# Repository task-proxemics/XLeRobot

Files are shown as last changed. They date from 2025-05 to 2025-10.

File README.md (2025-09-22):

# [XLeRobot 🤖](https://xlerobot.readthedocs.io/en/latest/index.html)




<a href="https://xlerobot.readthedocs.io/en/latest/index.html">
  front
</a>





---

**🚀 Bringing Embodied AI to Everyone - Cheaper Than an iPhone! 📱**  
**💵 Starts from $660 cost and ⏰ <4hrs total assembly time!!**

*Built upon the giants: [LeRobot](https://github.com/huggingface/lerobot), [SO-100/SO-101](https://github.com/TheRobotStudio/SO-ARM100), [Lekiwi](https://github.com/SIGRobotics-UIUC/LeKiwi), [Bambot](https://github.com/timqian/bambot)*

<table>
  <tr>
    <td></td>
    <td></td>
    <td></td>
  </tr>
  <tr>
    <td></td>
    <td></td>
    <td></td>
  </tr>
  <tr>
    <td></td>
    <td></td>
    <td></td>
  </tr>
</table>

---

# 📰 News 
- 2025-09-22: **Hardware Assembly Video Tutorial** availabe at [Youtube](https://www.youtube.com/watch?v=upB1CEFeOlk) and [Bilibili](https://www.bilibili.com/video/BV1AGWFzUEJf/). Thanks WOWROBO for making this video!
- 2025-09-09: **Developer Assembly kit (excluding battery and IKEA cart) ready for purchase** in [China (Taobao) for **3699￥**](https://e.tb.cn/h.SZFbBgZABZ8zRPe?tk=ba514rTBRjQ) and [world-wide for **579\$**](https://shop.wowrobo.com/products/xlerobot-dual-arm-mobile-household-robot-kit?variant=47297659961561). _(In collaboration with **Wowrobo**, one of the official collaborators with Huggingface SO101 arm, they have sold 5k+ SO101 arm worldwide with great customer feedback.)_
  
  - Non-profit, I personally don't earn any from this. I also asked Wowrobo to set the price as low as possible.
  - This is only the assembly kit for developers, please check documentation website and this repo for available codes and tutorials before you purchase.
- 2025-09-09: Joined [Embodied AI Home Robot Hackathon](https://www.seeedstudio.com/embodied-ai-worldwide-hackathon-home-robot.html) (Oct 25–26, Bay Area) held by **SEEED x Nvidia x Huggingface** as mentor! [Register HERE](https://docs.google.com/forms/d/e/1FAIpQLSdYYDegdgIypxuGJNLcoc8kbdmU4jKgl49zg4X-107LAmBN4g/viewform).
- 

- 2025-08-30: XLeRobot 0.3.0 Release with final outfit touch up and household chores showcase demos. 

- 2025-07-30: [Control XLeRobot in real life](https://xlerobot.readthedocs.io/en/latest/software/index.html) with **keyboard/Xbox controller/Switch joycon** in the wild anywhere. All bluetooth, no wifi needed and zero latency.
- rea

- 2025-07-08: [**Simulation**](https://xlerobot.readthedocs.io/en/latest/simulation/index.html) with updated urdfs, control scripts (support Quest3 VR, keyboard, Xbox controller, switch joycon), support for new hardware and cameras, RL environment. Get started in 15 min.
-  vr

- 2025-07-01: [**Documentation** website](https://xlerobot.readthedocs.io/en/latest/index.html) out for more orgainized tutorials, demos and resources.

- 2025-06-13: [**XLeRobot 0.2.0**](https://xlerobot.readthedocs.io) hardware setup, the 1st version fully capable for autonomous household tasks, starts from 660$. 

---

## 💵 Total Cost 💵

> [!NOTE] 
> Cost excludes 3D printing, tools, shipping, and taxes.

| Price (Buy all the parts yourself) | US | EU | CN | IN |
| --- | --- | --- | --- | --- |
| **Basic** (use your laptop, single RGB head cam) | **~$660** | **~€680** | **~¥3999** | **~₹87000** |
| ↑ Stereo dual-eye RGB head cam | +$30 | +€30 | +¥199 | +₹6550 |
| + RasberryPi | +$79 | +€79 | +¥399 | +₹7999 |
| ↑ RealSense RGBD head cam | +$220 | +€230 | +¥1499 | +₹35726 |

---
## 🚀 Get Started 🚀

> [!NOTE] 
> If you are totally new to programming, please spend at least a day to get yourself familiar with basic Python, Ubuntu and Github (with the help of Google and AI). At least you should know how to setup ubuntu system, git clone, pip install, use intepreters (VS Code, Cursor, Pycharm, etc.) and directly run commands in the terminals.

1. 💵 **Buy your parts**: [Bill of Materials](https://xlerobot.readthedocs.io/en/latest/hardware/getting_started/material.html)
2. 🖨️ **Print your stuff**: [3D printing](https://xlerobot.readthedocs.io/en/latest/hardware/getting_started/3d.html)
3. 🔨 ~~Avengers~~: [**Assemble**!](https://xlerobot.readthedocs.io/en/latest/hardware/getting_started/assemble.html)
4. 💻 **Software**: [Get your robot moving!](https://xlerobot.readthedocs.io/en/latest/software/index.html)

---

## Contribute

**👋 Want to contribute to XLeRobot?**
Please refer to [CONTRIBUTING.md](CONTRIBUTING.md) for guidance on how to get involved!

**Main Contributors**

- [Gaotian/Vector Wang](https://vector-wangel.github.io/)
- [Zhuoyi Lu](https://lzhuoyi.github.io/Zhuoyi_Lu.github.io/): RL sim2real deploy, teleop on real robot (Xbox, VR, Joycon)
- Yiyang Huang: RL & VLA implementation (ongoing)
- YCP: WebUI for remote control (ongoing)
- [Lixing Zhang](lixingzhang.com): Hardware design improvements
- Nicole Yue: Documentation website setup
- Yuesong Wang: Mujoco simulation

This is just a small brick in the pyramid, made possible by [LeRobot](https://github.com/huggingface/lerobot), [SO-100](https://github.com/TheRobotStudio/SO-ARM100), [Lekiwi](https://github.com/SIGRobotics-UIUC/LeKiwi), and [Bambot](https://github.com/timqian/bambot). Thanks to all the talented contributors behind these detailed and professional projects.

Looking forward to collaborating with anyone interested in contributing to this project!

## About me

[Gaotian/Vector Wang](https://vector-wangel.github.io/)

I am a CS graduate student at Rice University [RobotPi Lab](https://robotpilab.github.io/), focusing on robust object manipulation, where we propse virtual cages and funnels and physics-aware world models to close the Sim2real gap and achieve robust manipulation under uncertainties. One of my papers, Caging in Time, has recently been accepted by International Journal of Robotics Research (IJRR).

I built XLeRobot as a personal hobby to instantiate my research theory, also to provide a low-cost platform for people who are interested in robotics and embodied AI to work with. 

Star History Chart (https://star-history.com/#Vector-Wangel/XLeRobot&Timeline)
---

## Citation

If you want, you can cite this work with:

```bibtex
@misc{wang2025xlerobot,
    author = {Wang, Gaotian and Lu, Zhuoyi},
    title = {XLeRobot: A Practical Low-cost Household Dual-Arm Mobile Robot Design for General Manipulation},
    howpublished = "\url{https://github.com/Vector-Wangel/XLeRobot}",
    year = {2025}
}
```
---Generated Image August 27, 2025 - 4_58PM

## 🪧 Disclaimer 🪧

> [!NOTE]
> If you build, buy, or develop a XLeRobot based on this repo, you will be fully responsible for all the physical and mental damages it does to you or others.

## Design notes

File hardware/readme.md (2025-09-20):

Here stores the .3mf file of XLeRobot 0.3.0 for 3D printing.



Note that the 3D Printing files are only to store the models. It’s suggested to place, orient, and add supports yourself to ensure the best printing quality.

## Notes

- The .3mf file contains soft finray fingers that need to be printed with TPU95A. If you want original SO101 finger, just download the original SO101 .stl file.
- d2e57534a9e55a3d4dc0d644242cd044
- The .3mf file contains 2 version of the single RGB head camera connector and shell, one for webcam & realsense, the other for the cheaper camera same as the hand camera.
- 

- No need to adjust the base connector this time, just print the washers and insert them into the IKEA cart for the best base support.
- 

---

- Update 20.09.2025 by Lix: New gimbal designs can be found in the two mesh files:
    - Gimbal_Pitch_Holder_d435.stl: For Intel Realsense D435 or similar RGBD camera.
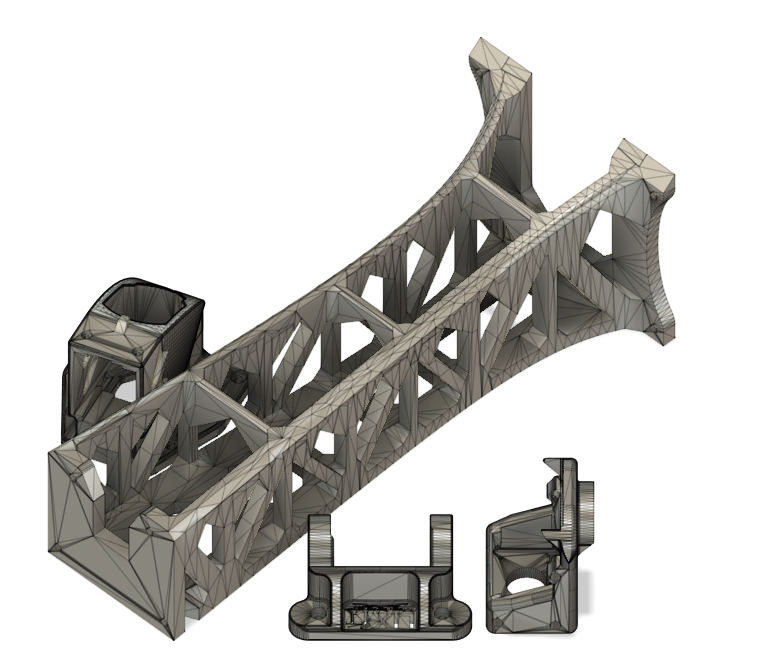
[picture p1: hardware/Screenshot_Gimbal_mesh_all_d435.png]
d435
    
    - Gimbal_Pitch_Holder_d455.stl: For Intel Realsense D455 or similar RGBD camera.
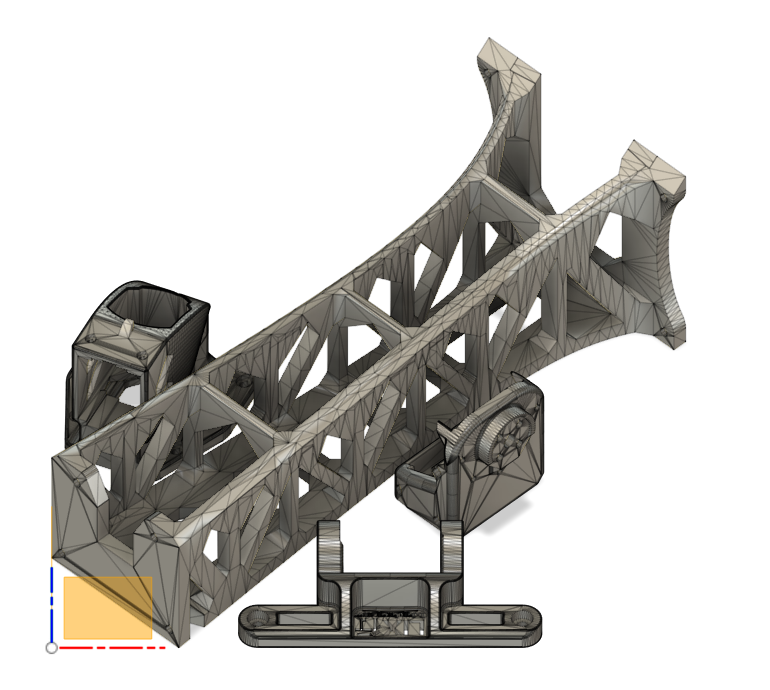
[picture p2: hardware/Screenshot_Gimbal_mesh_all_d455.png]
d455


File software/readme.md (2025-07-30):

## Updates

This folder mimics the official lerobot folder with XLeRobot robot file, configs and demo codes.

- SO100/SO101 control codes: These codes should be compatible to both SO100 and SO101, even if you just keep the name in the codes as so100. 

  - Keyboard Joint control
  - Keyboard EE control with my own analytical IK
  - Keyboard EE control for dual arm setup with my own analytical IK

- Computer Vision codes
  - simple_so100_yolo_ee_control.py: YOLO for object detection and segmentation, real-time tracking with the hand camera
  - 

Real-time test on YOLO-based control for object tracking:

https://github.com/user-attachments/assets/e0eb4aa5-bce2-404c-b9ed-380a83c852fd

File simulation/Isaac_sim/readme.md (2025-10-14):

Here's usd file for XLeRobot in Isaac Sim.

We are currently in collaboration with Lightwheel AI. 

And we highly recommend to run XLeRobot in Isaac Sim with their provided environment Leisaac.

https://github.com/LightwheelAI/leisaac

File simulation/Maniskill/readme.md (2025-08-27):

Here's the urdf files, assets, and EE control codes in Maniskill.

## Update

XLeRobot files are exclusively listed instead of borrowing fetch's name. So there are a few more modifications need to be done to run XLeRobot in the ReplicaCAD scene, in addtion to the [previous tutorial](https://xlerobot.readthedocs.io/en/latest/simulation/getting_started/index.html) 

For new robot ids, you need to add them to ReplicaCAD scene first.


As well as the agent/robots/init.py


## Run the examples

You also need to add the robot id in the command. For example, if you want to run a single-arm version of XLeRobot:

```
python -m mani_skill.examples.demo_ctrl_action_ee_keyboard_single -e "ReplicaCAD_SceneManipulation-v1" -r "xlerobot_single"  --render-mode="human" --shader="rt-fast" -c "pd_joint_delta_pos"
```

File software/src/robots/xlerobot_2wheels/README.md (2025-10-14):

# XLeRobot 2-Wheels (Differential Drive)

This is a modified version of XLeRobot that uses a 2-wheel differential drive base instead of the original 3-wheel omni wheel base.

## Key Changes from Original XLeRobot

### Hardware Changes
- **Wheels**: Reduced from 3 omni wheels to 2 differential drive wheels
- **Motor IDs**: 
  - Left wheel: Motor ID 9
  - Right wheel: Motor ID 10
  - Removed: Back wheel (previously Motor ID 8)

### Kinematics Changes
- **Movement**: Only supports forward/backward (x) and rotation (θ)
- **No lateral movement**: Cannot move sideways (y) like the omni wheel version
- **Differential drive equations**:
  - Left wheel speed = (v - ω*L/2) / r
  - Right wheel speed = (v + ω*L/2) / r
  - Where v = linear velocity, ω = angular velocity, L = wheelbase, r = wheel radius

### Configuration Parameters
- `wheel_radius`: 0.05 meters (default)
- `wheelbase`: 0.25 meters (default)
- These can be adjusted in the config files

### Control Interface
- **Forward/Backward**: 'i'/'k' keys
- **Rotate Left/Right**: 'u'/'o' keys
- **Speed Control**: 'n'/'m' keys (3 speed levels)
- **No lateral movement keys**: 'j'/'l' keys removed

## Usage

### Running the Host (on robot hardware)
```bash
PYTHONPATH=src python -m lerobot.robots.xlerobot_2wheels.xlerobot_2wheels_host --robot.id=my_xlerobot_2wheels
```

### Running the Teleop Client
```bash
PYTHONPATH=src python -m examples.xlerobot_2wheels.teleoperate_Keyboard
```

### Direct Connection (no ZMQ)
```python
from lerobot.robots.xlerobot_2wheels import XLerobot2Wheels, XLerobot2WheelsConfig

config = XLerobot2WheelsConfig()
robot = XLerobot2Wheels(config)
robot.connect()
```

## Files Structure

- `xlerobot_2wheels.py`: Main robot class with differential drive kinematics
- `xlerobot_2wheels_client.py`: ZMQ client for remote control
- `xlerobot_2wheels_host.py`: ZMQ host running on robot hardware
- `config_xlerobot_2wheels.py`: Configuration classes
- `__init__.py`: Package initialization

## Key Differences from Original

1. **State Features**: Removed `y.vel` from state features (only `x.vel` and `theta.vel`)
2. **Motor Configuration**: Only 2 base motors instead of 3
3. **Kinematics Functions**: 
   - `_body_to_wheel_raw()`: Implements differential drive forward kinematics
   - `_wheel_raw_to_body()`: Implements differential drive inverse kinematics
4. **Control Interface**: Simplified to only support differential drive movements

## Advantages of Differential Drive

1. **Simpler Hardware**: Only 2 wheels instead of 3
2. **Lower Cost**: Fewer motors and simpler mechanical design
3. **Easier Maintenance**: Less complex wheel system
4. **Better for Indoor**: More suitable for flat indoor environments

## Limitations

1. **No Lateral Movement**: Cannot move sideways without rotating first
2. **Less Maneuverable**: Requires more complex maneuvers for precise positioning
3. **Wheel Slip**: May experience wheel slip on uneven surfaces

## Migration from Original XLeRobot

To migrate from the original 3-wheel version:

1. Update motor IDs in hardware configuration
2. Remove the back wheel motor
3. Update control code to use only forward/backward and rotation commands
4. Adjust movement strategies to account for no lateral movement capability

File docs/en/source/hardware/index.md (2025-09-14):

# Hardware

## 💵 Total Cost 💵

> Cost excludes 3D printing, tools, shipping, and taxes.
> 

| Price | US | EU | CN | IN |
| --- | --- | --- | --- | --- |
| **Basic** (use your laptop, single RGB head cam) | **~$660** | **~€680** | **~¥3999** | **~₹87000** |
| ↑ Stereo dual-eye RGB head cam | +$30 | +€30 | +¥199 | +₹6550 |
| + RaspberryPi | +$79 | +€79 | +¥399 | +₹7999 |
| ↑ RealSense RGBD head cam | +$220 | +€230 | +¥1499 | +₹35726 |

## 🚀 Get Started 🚀

##### [🛒 Bill of Material](getting_started/material)

##### [🖨️ 3D Printing](getting_started/3d)

##### [🔨 Assembly](getting_started/assemble)

##### [🛠️ Hardware Intro](hardware_intro/index)

---

```{toctree}
:caption: Get started
getting_started/material
getting_started/3d
getting_started/assemble
```

```{toctree}
:caption: Hardware Intro
hardware_intro/index
```

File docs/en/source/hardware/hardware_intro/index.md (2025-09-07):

## 🛠️ Hardware Intro 🛠️

**XLeRobot** = Lekiwi + 1x SO-100/SO-101 arm + **IKEA RÅSKOG Cart** + **Anker Battery**

= 2x SO-100/SO-101 Arms + 3x omni wheels + RaspberryPi + **IKEA RÅSKOG Cart** + **Anker Battery**

#### 📜Basic Specs

- **Weight**📏: ~12kg. Easily lifted by an adult.
- **Workspace**🦾:
    - Height range: ~0.5m-1.25m from the ground
    - Width range: ~0.36m from the cart edge.
    - Capable of many household tasks.
- **Battery**🔋:
    - 300W max out: sufficient for powering 12V version dual arm + lekiwi base + RaspberryPi (~180W max)
    - 288Wh capacity: can normally operate for 10hrs+
    - 280W max in: 1hr to get fully charged
    - Optional solar panels☀: for endless recharging

> All computing is handled by your PC—Raspberry Pi only manages data communication via WiFi
>

#### Why IKEA RÅSKOG Cart?

- 🌎 Global availability with standardized design
- 💰 Cost-effective
- 🏗️ Simple yet sturdy construction
- 🔧 Metal mesh bottom enables easy component mounting
- 📦 Perfect for storage and transportation
- 📏 Ideal height for common household surfaces—from stovetop to coffee table
- 📏 Compact footprint fits in nearly any room (thanks to IKEA's thoughtful design)

#### Why Anker SOLIX C300 Power Station?

- 🌍 Global availability
- ⚡ 288Wh capacity, 300W maximum output power, 280W maximum charging power
- 🔌 Powers both 12V arms, base, and Raspberry Pi at full capacity through three USB-C charging cables—eliminating complex wiring
- 🔋 Exceptional battery life: 12+ hours normal use, 8 hours intensive operation, 1-hour full charge
- 💡 Integrated lighting for nighttime operation
- ☀️ Optional solar panel mounting for continuous power supply
- 🎒 Versatile and detachable—doubles as emergency backup power or camping power source

Any battery/power bank/power station that supports two 60W+ USB-C fast charging should work. Here are some other potential options (not tested), these brands should be available both in US and China.
  - [UGREEN 300W 48000mAh Power Bank](https://www.ugreen.com/products/ugreen-300w-48000mah-portable-charger-power-bank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)
  - [Anker Laptop Power Bank (25K, 165W)](https://www.anker.com/products/a1695-anker-power-bank-25000mah-165w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)
  - [AOHI 240W Laptop Power Bank 27600mAh](https://a.co/d/aW8lNc2)

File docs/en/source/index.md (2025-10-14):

# XLeRobot 

    

<!-- [![en](https://img.shields.io/badge/lang-en-blue.svg)](..)
[![中文](https://img.shields.io/badge/lang-中文-brown.svg)](README_CN.md)

<div class="lang-switch">
  <a onclick="switchLang('en')" class="active">
    <img src="https://img.shields.io/badge/lang-en-blue.svg" alt="English" />
  </a>
  <a onclick="switchLang('zh')">
    <img src="https://img.shields.io/badge/lang-中文-brown.svg" alt="中文" />
  </a>
</div>

<div class="lang-en">
[English content...]
</div>

<div class="lang-zh">
[Chinese content...]
</div> -->



## Intro

**🚀 Bring Embodied AI to Every Family Around the World! Cheaper than iPhone📱!**

**⏰ <4hrs total assembly time**

*Built upon the giants: [LeRobot](https://github.com/huggingface/lerobot), [SO-100/SO-101](https://github.com/TheRobotStudio/SO-ARM100), [Lekiwi](https://github.com/SIGRobotics-UIUC/LeKiwi), [Bambot](https://github.com/timqian/bambot)*

---

<video width="100%" controls>
  <source src="https://vector-wangel.github.io/XLeRobot-assets/videos/Real_demos/xlerobot030.mp4" type="video/mp4">
  Your browser does not support the video tag.
</video>

## 📰 News 
- 2025-09-22: **Hardware Assembly Video Tutorial** availabe at [Youtube](https://www.youtube.com/watch?v=upB1CEFeOlk) and [Bilibili](https://www.bilibili.com/video/BV1AGWFzUEJf/). Thanks WOWROBO for making this video!
- 2025-09-09: **Developer Assembly kit (excluding battery and IKEA cart) ready for purchase** in [China (Taobao) for **3699￥**](https://e.tb.cn/h.SZFbBgZABZ8zRPe?tk=ba514rTBRjQ) and [world-wide for **579\$**](https://shop.wowrobo.com/products/xlerobot-dual-arm-mobile-household-robot-kit?variant=47297659961561). _(In collaboration with **Wowrobo**, one of the official collaborators with Huggingface SO101 arm, they have sold 5k+ SO101 arm worldwide with great customer feedbacks.)_
  
  - Non-profit, I personally don't earn any from this. I also asked Wowrobo to set the price as low as possible.
  - This is only the assembly kit for developers, please check documentation website and this repo for available codes and tutorials before you purchase.
- 2025-09-09: Joined [Embodied AI Home Robot Hackathon](https://www.seeedstudio.com/embodied-ai-worldwide-hackathon-home-robot.html) (Oct 25–26, Bay Area) held by **SEEED x Nvidia x Huggingface** as mentor! [Register HERE](https://docs.google.com/forms/d/e/1FAIpQLSdYYDegdgIypxuGJNLcoc8kbdmU4jKgl49zg4X-107LAmBN4g/viewform).
- 

- 2025-08-30: XLeRobot 0.3.0 Release with final outfit touch up and household chores showcase demos. 

- 2025-07-30: [Control XLeRobot in real life](https://xlerobot.readthedocs.io/en/latest/software/index.html)  with **keyboard/Xbox/Switch joycon** in the wild (bluetooth, no wifi, 0 latency).
- rea

- 2025-07-08: [**Maniskill Simulation**](https://xlerobot.readthedocs.io/en/latest/simulation/index.html) with URDFs, control scripts (support Quest3 VR, keyboard, Xbox, Switch Joycon). 
Supports for multiple sensors (depth, segmentation, tactile, etc), RL/IL/VLA environments. Get started in 15 min.
-  vr

- 2025-07-01: [**Documentation** website](https://xlerobot.readthedocs.io/en/latest/index.html) out for more organized tutorials, demos and resources.

- 2025-06-13: [**XLeRobot 0.2.0**](https://xlerobot.readthedocs.io) hardware setup fully capable for household tasks, with 660$ cost. 

---
## Cost

| Price (Buy Parts Yourself) | US | EU | CN | IN |
| --- | --- | --- | --- | --- |
| **Basic** (use your laptop, single RGB head cam) | **~$660** | **~€680** | **~¥3999** | **~₹87000** |
| ↑ Stereo dual-eye RGB head cam | +$30 | +€30 | +¥199 | +₹6550 |
| + RaspberryPi | +$79 | +€79 | +¥399 | +₹7999 |
| ↑ RealSense RGBD head cam | +$220 | +€230 | +¥1499 | +₹35726 |

Assembly kit ready for purchase soon, stay tuned!

## 🌟 Why XLeRobot? 🌟

**XLeRobot = XL + LeRobot**

### Why "LeRobot" Core?

- **Cheap Materials** 💴: 90% 3D printed components with affordable motors and electronics.
- **Easy Assembly** 🔨: 67 min to assemble 2 SO101 arms and configure motors.
- **Plug-&-Play** 🧩: Get robots running with simple pip install and a few lines of code.
- **Thriving LeRobot Community** 🌍:
World's largest low-cost robotics community featuring
    - Multiple [SOTA VLA models🧠](https://huggingface.co/lerobot), datasets📊, and tools🔨 ready for deployment.
    - 10k+ members for brainstorming and discussions🧑‍🤝‍🧑.

### Why "XL" Enhancement?



- 🏠 The field/market lacks affordable, stable, dual-arm home robots that match LeRobot's ease of assembly.
- 🖨️ Traditional 3D printed chassis suffer from limited durability, stability, and load capacity — impractical for daily use.
- ⚡ DIY mobile robots face power supply challenges, leading to complex wiring setups.

### Overall Advantages

- **Cost-effective** 💴: Complete build costs \$660, or directly upgrade from your SO101 Arm and Lekiwi for \$250.
- **Easy upgrade** ⏫ from **Lekiwi** and **SO-100/SO-101**
    - Hardware: No motor ID changes or mods needed
    - Software: Same tabletop single/dual-arm setup—transfer your policies directly from SO101 arm
- **Practical and reliable** 💪: Performs many daily tasks comparable to $30,000 closed-source robots.
    - More tasks demonstrated in the [**Huggingface LeRobot World-wide Hackathon**](https://huggingface.co/spaces/LeRobot-worldwide-hackathon/all-winners).
    - **Note**: Not currently designed for in-hand dexterity 🤹, heavy lifting (over 1kg per arm) 🏋️, or highly dynamic movements (catch ball) 🏃
- **Rich open-source resources** 📕
    - LeRobot's plug-and-play code🧩 and extensive AI model library🧠
    - Backed by an active, growing community of contributors🧑‍🤝‍🧑
- **⚠️Safety always matters⚠️**: XLeRobot has inherent physical hardware limitations (low-torque motors, short arm length, wheel-based), making it **physically** almost incapable of harming humans, while still maintaining its ability to perform many household tasks.

---

## 🎯 Who is XLeRobot For?

- 🚀 **Startups & Labs**: Build prototypes faster with one of the world's cheapest general robotics platform
- 👩🔬 **Self Researchers**: Experiment with embodied AI without breaking the bank 💸
- 🎓 **Educators**:
    - High School Teachers: Bring cutting-edge robotics to STEM classes 🧪
    - University Professors: Affordable platform for robotics/AI courses 📚
    - Students: From beginners to researchers 🎒→🎓
- 🤖 **DIY Enthusiasts**: Perfect for indoor projects - plant care, delivery bots, home automation 🌱📦

---

## Limitations

(Hey, for this price, what more could you ask for?)

- 🔒 Fixed height—adding a stable lifting platform would significantly increase cost and assembly difficulty
- 📏 Smaller workspace compared to Aloha—while we try to maximize the SO101 workspace, the arm has size limitations (~40cm reach), though XLeRobot still handles most tasks effectively
- ⚖️ Limited payload capacity (600~1000g) for a single arm

However, with all considered — cost, community support, ease of assembly, and practical utility — XLeRobot stands out as one of the most compelling low-cost robot for indoor application!

---

## Contribute

**👋 Want to contribute?**
Please refer to [CONTRIBUTING.md](CONTRIBUTING.md) for guidance on how to get involved!

** Main Contributors **

- [Gaotian/Vector Wang](https://vector-wangel.github.io/)(myself)
- Zhuoyi Lu: RL sim2real deploy, teleop on real robot (Xbox, VR, Joycon)
- Nicole Yue: Documentation website setup
- Yuesong Wang: Mujoco simulation assets

This is just a small brick in the pyramid, made possible by [LeRobot](https://github.com/huggingface/lerobot), [SO-100](https://github.com/TheRobotStudio/SO-ARM100), [Lekiwi](https://github.com/SIGRobotics-UIUC/LeKiwi), and [Bambot](https://github.com/timqian/bambot). Thanks to all the talented contributors behind these detailed and professional projects.

Looking forward to collaborating with anyone interested in contributing to this project!

---

## Citation

If you want, you can cite this work with:

```
@misc{wang2025xlerobot,
    author = {Wang, Gaotian and Lu, Zhuoyi},
    title = {XLeRobot: A Practical Low-cost Household Dual-Arm Mobile Robot Design for General Manipulation},
    howpublished = "\\url{<https://github.com/Vector-Wangel/XLeRobot>}",
    year = {2025}
}

```

---

## 🪧 Disclaimer 🪧

> If you build, buy, or develop a XLeRobot based on this repo, you will be fully responsible for all the physical and mental damages it does to you or others.
>



---

```{toctree}
:maxdepth: 1
hardware/index
simulation/index
software/index
demos/index
relatedworks/index
```

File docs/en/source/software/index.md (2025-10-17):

<!-- THIS IS ALL GENERATED DOCUMENTATION via generate_robot_docs.py. DO NOT MODIFY THIS FILE DIRECTLY. -->

# Software

Here we will show how to run XLeRobot under the lerobot framework.

### [Install LeRobot 🤗 and Move XLeRobot files](getting_started/install.md)

### Quick Guide

```{note}
If you haven't played with lerobot SO101 Arm before, it's recommended to test single arm setup teleop and play with it for a while first.
```

1. **Choose Control Method**: Joint control (example 0) for basic motor testing, end-effector control for teleop (example 1 & 6)
2. **Advanced Features**: Try dual-arm control (example 2) or vision-based control (example 3) for more complex tasks
3. **Full System**: Use keyboard (example 4), Xbox controller (example 5), or Switch Joycon (example 7) for complete XLeRobot teleop

All example scripts are located in the [`software/examples/`](https://github.com/Vector-Wangel/XLeRobot/tree/main/software/examples) directory and can be run directly after proper setup and calibration. Some examples needs additional calibration to ensure performance.

```{note}
For basic version of XLeRobot, you don't need a RaspberryPi. Just use your laptop and put it in the IKEA cart if you want to use the full system.
```

### [SO100/SO101 Arm Examples](getting_started/SO101.md)

### [XLeRobot Teleop](getting_started/XLeRobot_teleop.md)

### [Autonomous LLM Agent](getting_started/LLM_agent.md)

### [Reinforcenment Learning (RL) & VLA](getting_started/RL_VLA.md)

### [Raspberri Pi Setup](getting_started/raspberry_pi_setup.md)

```{toctree}
getting_started/install
getting_started/SO101
getting_started/XLeRobot_teleop
getting_started/LLM_agent
getting_started/RL_VLA
getting_started/raspberry_pi_setup.md
```

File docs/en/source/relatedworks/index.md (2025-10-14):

# Related Works

🤗Here are all the works, both from robotics research and from the LeRobot community, that I found interesting, meaningful, and have potential for future applications on XLeRobot.

## Blogs

[Analytical IK for SO101](https://vectorwang.notion.site/Analytical-IK-for-SO101-20abb280f59380d288bcdd398ffbfab1?pvs=25)

### 👀 Perception 

#### DRAWER: Convenient Real2Sim with Articulations

[DRAWER: Digital Reconstruction and Articulation with Environment Realism](https://xiahongchi.github.io/DRAWER/)

<video width="100%" controls>
  <source src="https://vector-wangel.github.io/XLeRobot-assets/videos/Other_works/DRAWER.mp4" type="video/mp4">
  Your browser does not support the video tag.
</video>

#### CoTracker

[CoTracker3: Simpler and Better Point Tracking by Pseudo-Labelling Real Videos](https://cotracker3.github.io/)

### 🧠 High-level Task Planning 

#### VJEPA-2: A Self-supervised Foundation World Model

[Introducing V-JEPA 2](https://ai.meta.com/vjepa/)

<video width="100%" controls>
  <source src="https://vector-wangel.github.io/XLeRobot-assets/videos/Other_works/VJEPA2.mp4" type="video/mp4">
  Your browser does not support the video tag.
</video>

### 🙌 Low-level Motion Control

#### HIL-SERL: Current SOTA (personal opinion) for RL

[HIL-SERL: Precise and Dexterous Robotic Manipulation via Human-in-the-Loop Reinforcement Learning](https://hil-serl.github.io/)

[HIL-SERL LeRobot Training Guide](https://huggingface.co/docs/lerobot/hilserl)

#### Caging in Time: A Planning Framework for Robust Object Manipulation

[Caging in Time: A Framework for Robust Object Manipulation under Uncertainties and Limited Robot Perception](https://journals.sagepub.com/doi/pdf/10.1177/02783649251343926)

<video width="100%" controls>
  <source src="https://vector-wangel.github.io/XLeRobot-assets/videos/Other_works/CIT.mp4" type="video/mp4">
  Your browser does not support the video tag.
</video>

### 👨‍🔧 Hardware

#### 3D Vitac: Low-cost Velostat Tactile Sensor

[3D-ViTac: Learning Fine-Grained Manipulation with Visuo-Tactile Sensing](https://binghao-huang.github.io/3D-ViTac/)

<video width="100%" controls>
  <source src="https://vector-wangel.github.io/XLeRobot-assets/videos/Other_works/3D-Vitac.mp4" type="video/mp4">
  Your browser does not support the video tag.
</video>

#### E-flesh: Low-cost Magnetic Tactile Sensor

[eFlesh: Highly customizable Magnetic Touch Sensing using Cut-Cell Microstructures](https://e-flesh.com)

<video width="100%" controls>
  <source src="https://vector-wangel.github.io/XLeRobot-assets/videos/Other_works/eflesh.mp4" type="video/mp4">
  Your browser does not support the video tag.
</video>

#### BACH hand: Belt-driven Active Surface Finger 

[Belt–Augmented Compliant Hand](https://yuanshenli.com/bach.html)

BACH hand demo

### 💻 Simulation

#### Maniskill: Light-weight GPU-accelerated Manipulation-focused Simulator

[ManiSkill — ManiSkill 3.0.0b21 documentation](https://maniskill.readthedocs.io/en/latest/)

#### RoboTwin: Large bimanual Manipulation Benchmark based on Maniskill

[RoboTwin 2.0: A Scalable Data Generator and Benchmark with Strong Domain Randomization for Robust Bimanual Robotic Manipulation](https://robotwin-platform.github.io/)

### 🧑‍🍳 Developing

#### Bambot: Web-based Control Panel 

[BamBot by Tim Qian](https://bambot.org/)

[BamBot Feetech Servo Control Panel - feetech.js](http://bambot.org/feetech.js)

#### Model Context Protocol (MCP)

- [Using MCP on Lerobot SO101 arm](https://github.com/IliaLarchenko/robot_MCP)
- [The official website of MCP](https://modelcontextprotocol.io/introduction)

#### 3D-reconstruction

[Hunyuan3D-2](https://huggingface.co/spaces/tencent/Hunyuan3D-2)

#### Maniskill Sim2real RL

[lerobot-sim2real by Stone Tao](https://github.com/StoneT2000/lerobot-sim2real)

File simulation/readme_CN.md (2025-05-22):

# XLeRobot Playground 分步指南

这是键盘EE控制的完整视频

https://github.com/user-attachments/assets/b8e630bd-1133-4941-acd1-d974f60098ff

## 前提条件

- Ubuntu操作系统
- 基本熟悉终端命令
- [Miniconda](https://docs.anaconda.com/free/miniconda/index.html)（推荐）

## 安装

### 1. 创建Conda环境

如果你已经有一个`lerobot`的conda环境，你可以使用它。否则，创建一个新环境：

```bash
conda create -y -n lerobot python=3.10
conda activate lerobot
```

> **注意**：建议将ManiSkill和lerobot代码放在同一环境中，以便未来的sim2real部署。

### 2. 安装ManiSkill

按照[官方安装说明](https://maniskill.readthedocs.io/en/latest/user_guide/getting_started/installation.html)安装ManiSkill。

```bash
# 基本安装
pip install mani-skill

# 下载场景数据集
python -m mani_skill.utils.download_asset "ReplicaCAD"
```

#### 2.1 如果数据集下载出错，请使用：

```bash
git clone https://huggingface.co/datasets/haosulab/ReplicaCAD
```
直接从huggingface下载数据集。然后文件夹内容应该放到

```bash
~/.maniskill/data/scene_datasets/replica_cad_dataset
```

#### 2.2 使用[快速入门指南](https://maniskill.readthedocs.io/en/latest/user_guide/getting_started/quickstart.html)和[演示脚本](https://maniskill.readthedocs.io/en/latest/user_guide/getting_started/quickstart.html)熟悉ManiSkill。尝试这个命令来测试你是否成功安装了Maniskill：
```bash
python -m mani_skill.examples.demo_random_action -e "ReplicaCAD_SceneManipulation-v1" \
  --render-mode="human" --shader="rt-fast"
```
### 3. 额外依赖

```bash
pip install pygame
```

### 4. 替换机器人文件

导航到你conda环境中的ManiSkill包文件夹：

```bash
cd ~/miniconda3/envs/lerobot/lib/python3.10/site-packages/mani_skill
```

用XLeRobot文件替换fetch机器人代码和资源：

1. 替换/agents和/assets中的文件：



2. 将控制代码添加到/examples：


## 使用方法

### 关节控制

运行关节控制演示：

```bash
python -m mani_skill.examples.XLeRobot_demo_joint_ctrl -e "ReplicaCAD_SceneManipulation-v1"   --render-mode="human" --shader="rt-fast" -c "pd_joint_delta_pos_dual_arm"
```

### 末端执行器控制

运行末端执行器控制演示：

```bash
python -m mani_skill.examples.XLeRobot_demo_ee_ctrl -e "ReplicaCAD_SceneManipulation-v1"   --render-mode="human" --shader="rt-fast" -c "pd_joint_delta_pos_dual_arm"
```

### 5. 可用环境

你可以按照[这个指南](https://maniskill.readthedocs.io/en/latest/user_guide/datasets/scenes.html)在XLeRobot中使用各种环境：

- `ReplicaCAD_SceneManipulation-v1`（默认）
- AI2THOR场景
- Robocasa厨房台面场景
- `OpenCabinetDrawer-v1`


### 6. VR集成

要启用Oculus VR：

1. 根据[官方文档](https://github.com/rail-berkeley/oculus_reader)安装Oculus读取器
2. 用`codes/VR/reader.py`中提供的版本替换reader.py文件：
3. 在你的配置中更新Oculus读取器文件夹的路径：

4. 将控制代码放入`examples/`后，运行末端执行器控制演示：

```bash
python -m mani_skill.examples.XLeRobot_demo_VR_ee_ctrl -e "ReplicaCAD_SceneManipulation-v1"   --render-mode="human" --shader="rt-fast" -c "pd_joint_delta_pos_dual_arm"
```

### 7. 自定义硬件集成

要使用不同的硬件版本：

1. 修改`agents/robots/fetch.py`中的URDF路径，以匹配`assets/`中的文件
2. 根据你的硬件配置，你可能需要调整`qpos`的大小


## 故障排除

### 常见错误

- 导航到脚本并更改链接名称
- 导航到脚本并注释掉避免碰撞列表

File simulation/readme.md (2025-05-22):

# Step-by-step Guide for XLeRobot Playground

Here's the full video for keyboard EE control

https://github.com/user-attachments/assets/b8e630bd-1133-4941-acd1-d974f60098ff

## Prerequisites

- Ubuntu operating system
- Basic familiarity with terminal commands
- [Miniconda](https://docs.anaconda.com/free/miniconda/index.html) (recommended)

## Installation

### 1. Create a Conda Environment

If you already have a `lerobot` conda environment, you can use that. Otherwise, create a new environment:

```bash
conda create -y -n lerobot python=3.10
conda activate lerobot
```

> **Note**: It's recommended to have ManiSkill and lerobot code in the same environment for future sim2real deployment.

### 2. Install ManiSkill

Follow the [official installation instructions](https://maniskill.readthedocs.io/en/latest/user_guide/getting_started/installation.html) for ManiSkill.

```bash
# Basic installation
pip install mani-skill

# Download scene dataset
python -m mani_skill.utils.download_asset "ReplicaCAD"
```

#### 2.1 If the dataset downloading goes wrong, use:

```bash
git clone https://huggingface.co/datasets/haosulab/ReplicaCAD
```
to directly download the dataset from huggingface. And then folder contents should go to

```bash
~/.maniskill/data/scene_datasets/replica_cad_dataset
```

#### 2.2 Familiarize yourself with ManiSkill using the [quickstart guide](https://maniskill.readthedocs.io/en/latest/user_guide/getting_started/quickstart.html) and [demo scripts](https://maniskill.readthedocs.io/en/latest/user_guide/getting_started/quickstart.html). Try this command to test whether you have successfully installed Maniskill:
```bash
python -m mani_skill.examples.demo_random_action -e "ReplicaCAD_SceneManipulation-v1" \
  --render-mode="human" --shader="rt-fast"
```
### 3. Additional Dependencies

```bash
pip install pygame
```

### 4. Replace Robot Files

Navigate to the ManiSkill package folder in your conda environment:

```bash
cd ~/miniconda3/envs/lerobot/lib/python3.10/site-packages/mani_skill
```

Replace the fetch robot code and assets with the XLeRobot files:

1. Replace the files in /agents and /assets:



2. Add control code to /examples:


## Usage

### Joint Control

Run the joint control demo with:

```bash
python -m mani_skill.examples.XLeRobot_demo_joint_ctrl -e "ReplicaCAD_SceneManipulation-v1"   --render-mode="human" --shader="rt-fast" -c "pd_joint_delta_pos_dual_arm"
```

### End Effector Control

Run the end effector control demo with:

```bash
python -m mani_skill.examples.XLeRobot_demo_ee_ctrl -e "ReplicaCAD_SceneManipulation-v1"   --render-mode="human" --shader="rt-fast" -c "pd_joint_delta_pos_dual_arm"
```

### 5. Available Environments

You can use various environments with XLeRobot following [this](https://maniskill.readthedocs.io/en/latest/user_guide/datasets/scenes.html):

- `ReplicaCAD_SceneManipulation-v1` (default)
- AI2THOR scenes
- Robocasa Kitchen counter scenes
- `OpenCabinetDrawer-v1`


### 6. VR Integration

To enable VR with Oculus:

1. Install Oculus reader according to the (official documentation)[https://github.com/rail-berkeley/oculus_reader]
2. Replace the reader.py file with the provided version in `codes/VR/reader.py`:
3. Update the path of the Oculus reader folder in your configuration:

4. After putting the control code to `examples/`, run the end effector control demo with:

```bash
python -m mani_skill.examples.XLeRobot_demo_VR_ee_ctrl -e "ReplicaCAD_SceneManipulation-v1"   --render-mode="human" --shader="rt-fast" -c "pd_joint_delta_pos_dual_arm"
```

### 7. Custom Hardware Integration

To use different hardware versions:

1. Modify the URDF path in `agents/robots/fetch.py` to follow the files in `assets/`
2. You may need to adjust the size of `qpos` depending on your hardware configuration


## Troubleshooting

### Common Errors

- Navigate to the script and change the link name
- Navigate to the script and comment out the avoid collision list

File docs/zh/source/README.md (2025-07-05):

# XLeRobot 🤖

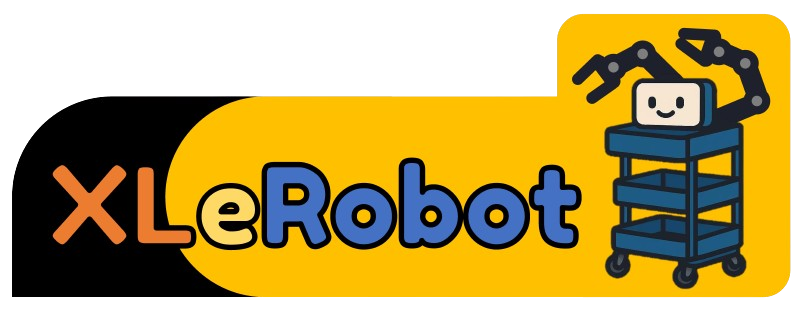
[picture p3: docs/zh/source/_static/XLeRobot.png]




<!-- [![es](https://img.shields.io/badge/lang-es-green.svg)](README_ES.md)
[![de](https://img.shields.io/badge/lang-de-orange.svg)](README_DE.md)
[![fr](https://img.shields.io/badge/lang-fr-white.svg)](README_FR.md)
[![日本語](https://img.shields.io/badge/lang-日本語-yellow.svg)](README_JP.md) -->

> [!NOTE] 
> 硬件：[XLeRobot 0.2.0的硬件配置](https://github.com/Vector-Wangel/XLeRobot/blob/main/XLeRobot_0_2_0_hardware/README.md)正式发布！这是第一个官方硬件版本，完全能够执行自主家务任务，成本低于1000美元。

> [!NOTE] 
> 仿真：**XLeRobot 0.1.5** 正式发布！当前版本包含 [一篇简短的技术博客](simulation/sim_CN.md) and 和详细的 [**分步安装指南**](simulation/sim_guide_CN.md), 并附带所有urdf文件和控制脚本，让您可以在10分钟内开始使用复现demo。 

> [!NOTE] 
> 实机：**XLeRobot 0.1.0** 正式发布！当前版本包括详细的**材料清单**、**3D打印模型和说明**，以及**逐步组装指南**。可用Lekiwi代码库在单臂版本上**运行遥操作测试**（由另一个跟随臂控制）。不到4000元，不到4小时即可复现demo。

# XLeRobot 🤖

  
---

**🚀 让具身AI走向每个人 - 比小米手机还便宜！ 📱**  
**💵 <4000￥ 和 ⏰ <4小时总组装时间!!**

*站在巨人的肩膀上: [LeRobot](https://github.com/huggingface/lerobot), [SO-100](https://github.com/TheRobotStudio/SO-ARM100), [Lekiwi](https://github.com/SIGRobotics-UIUC/LeKiwi), [Bambot](https://github.com/timqian/bambot)*

---
## ⚽ XLeRobot Playground （0.1.5）

**XLeRobot 0.1.5** 正式发布！当前版本包含 [一篇简短的技术博客](simulation/sim_CN.md) and 和详细的 [**分步安装指南**](simulation/sim_guide_CN.md), 并附带所有urdf文件和控制代码，让您可以在10分钟内开始使用并复现下面展示的demo。 

<video width="100%" controls>
  <source src="https://github.com/user-attachments/assets/e66d8cb5-7a02-4445-b6d9-793057996f87" type="video/mp4">
  Your browser does not support the video tag.
</video>

---

## 🌟 为什么选择XLeRobot？ 🌟
让我们来分解一下，因为**XLeRobot = XL + LeRobot**

<table>
  <tr>
    <td>
      
### 为什么选择"LeRobot"核心？
- **廉价材料** 💴: 90%的3D打印组件，配合经济实惠的电机和电子元件。
- **简易组装** 🔨: 仅需2小时的组装时间。
- **即插即用** 🧩: 通过简单的pip安装和几行代码让机器人运行起来。
- **蓬勃发展的LeRobot社区** 🌍:
  世界上最大的低成本机器人社区，特色包括
  - 多个[最先进的预训练AI模型🧠](https://huggingface.co/lerobot)、数据集📊和工具🔨，随时可以部署。
  - 

  - 6,000+聪明才智的头脑进行头脑风暴和讨论🧑‍🤝‍🧑。
    
    </td>
    </tr>
    <tr>
    <td>
 
### 为什么需要"XL"增强？ 
- 🏠 该领域/市场缺乏价格合理、稳定的双臂家用机器人，能够与LeRobot的简易组装相匹配。
- 🖨️ 传统3D打印底盘耐久性、稳定性和负载能力有限——使其不适合日常使用。
- ⚡ DIY移动机器人面临电源供应挑战，导致复杂的接线设置。
- 🤖 **XLeRobot**保持与LeRobot社区的桌面双臂SO100配置的兼容性，实现代码和策略的无缝转移。
  
    </td>
  </tr>
 </table>       



### XLeRobot的整体优势/目标

- **经济实惠** 💴: 完整构建成本为$660，或者从现有SO100Arm和Lekiwi升级仅需$250。
- **轻松升级** ⏫ (物理和电气)对于**Lekiwi**和**SO100**
    - 硬件：无需更改电机ID或硬件修改
    - 软件：与桌面单臂/双臂设置相同——直接从SO100臂转移您训练好的策略
- **实用可靠** 💪: 执行许多日常任务，可与市场上$20,000的替代品相媲美。
 
    - 更多任务在LeRobot黑客马拉松中展示，包括[深圳](https://www.youtube.com/watch?v=_r9v04Rc3xA&ab_channel=SeeedStudio)、[上海](https://www.youtube.com/watch?v=1oXvINlYsls&ab_channel=SeeedStudio)和[圣何塞](https://www.youtube.com/watch?v=QvzhsDliGII&ab_channel=SeeedStudio)([获奖者](https://www.hackster.io/contests/embodiedAI#winners))，以及[第一个](https://www.youtube.com/watch?v=i3D94400vq0&ab_channel=HuggingFace)。
    - **注意**：目前不适用于手内灵巧操作🤹、重物提升(每臂超过1kg)🏋️或高度动态运动🏃
- **丰富的开源资源** 📕
    - LeRobot的即插即用代码🧩和广泛的AI模型库🧠
    - 由活跃、不断增长的贡献者社区支持🧑‍🤝‍🧑
- **⚠️安全始终重要⚠️**: XLeRobot具有固有的物理硬件限制(低扭矩电机、短臂长、轮式基础)，使其几乎不可能伤害人类，同时仍然保持执行许多家庭任务的能力。
  - **低扭矩电机**🦾: 即使在意外接触的情况下，机器人也极不可能造成伤害。此外，其扭矩限制防止其执行高速、动态运动。
  - **短臂长**🦵: 在不太可能的情况下，如果它持有尖锐物体，可以通过翻倒IKEA推车快速禁用机器人。
  - **轮式基础**🧑‍🦼‍➡️: 它无法爬过高于10cm的障碍物，所以在未授权访问尝试的情况下，您可以使用障碍物或楼梯轻松限制其移动。

Examples

这些👆是摆拍照片，但它们展示了XLeRobot平台在其硬件限制内可以实现的功能。(场景有点凌乱，但嘿，这就是生活！)

---
## 🎯 演示 0.1.0 🎯
> [!NOTE]
> 目前是**单臂版本**实现Lekiwi，由另一个跟随臂以**3倍速度**远程操作。

https://github.com/user-attachments/assets/2e9eb3c9-af16-4af2-8748-8f936278c8eb

---

## 💵 总成本 💵

> [!NOTE] 
> 成本不包括3D打印、工具、运输和税费。

| 价格| 美国  | 欧盟  | 中国 |
|---|----:|----:|----:|
| **从零开始构建** |  **~$660**  |  **~€650**  |  **~¥3900**  |
| **从2个SO100臂升级**  |  **~$400**  |  **~€440**  |  **~¥2400**  |
| **从1个Lekiwi(底座+臂)升级** |  **~$370**  |  **~€350**  |  **~¥1900**  |
| **从1个Lekiwi和1个SO100臂升级** |  **~$250**  |  **~€240**  |  **~¥1200**  |

详情请参见[材料清单](BOM.md)。

---
---
## 🚀 开始使用 🚀
> [!NOTE] 
> 我自己也是硬件新手，所以我想让这个教程对所有同为初学者的朋友友好。

> [!NOTE] 
> 如果你完全不懂编程，请至少花一天时间熟悉基本的Python、Ubuntu和Github(借助B站和AI的帮助)。至少你应该知道如何设置ubuntu系统、git克隆、pip安装、使用解释器(VS Code、Cursor、Pycharm等)，Conda环境，以及直接在终端中运行命令。

1. 💵 **购买零件**: [材料清单](BOM.md)
2. 🖨️ **打印你的部件**: [3D打印](3Dprint.md)
3. 🔨 ~~复仇者~~: [**集结**!](Assembly.md)
4. 💻 **软件**: [让你的机器人动起来!](Software.md)
---
---
> [!NOTE] 
> 上面的内容提供了构建**XLeRobot**的高效指导。下面的内容更详细地解释了项目的目的和愿景。

## 🛠️ 硬件介绍 🛠️

**XLeRobot** = Lekiwi + 1x SO100臂 + **宜家RÅSKOG推车** + **Anker电池**

= 2x SO100臂 + 3x全向轮 + 树莓派 + **宜家RÅSKOG推车** + **Anker电池**

### 📜基本规格

- **重量**📏: ~12kg。成人可轻松抬起。
- **工作空间**🦾:
  - 高度范围: 距地面~0.5m-1.25m
  - 宽度范围: 距推车边缘~0.36m。
  - 能够完成许多家庭任务。
- **电池**🔋:
  - 300W最大输出: 足以为12V版本双臂 + lekiwi底座 + 树莓派(~180W最大)供电
  - 288Wh容量: 通常可运行10小时以上
  - 280W最大输入: 1小时即可充满
  - 可选太阳能板☀: 用于无限充电

> [!NOTE]
> *所有计算都由你的PC处理——树莓派仅通过WiFi管理数据通信 📶*

<table>
  <tr>
    <td>
      
### 为什么选择宜家RÅSKOG推车？
- 🌎 全球可用，设计标准化
- 💰 经济实惠
- 🏗️ 结构简单但坚固
- 🔧 金属网格底部便于组件安装
- 📦 完美适合存储和运输
- 📏 理想高度适合常见家庭表面——从炉灶到咖啡桌
- 📏 紧凑的占地面积几乎适合任何房间(感谢宜家的周到设计)

    </td>
    </tr>
    <tr>
    <td>
    
### 为什么选择Anker SOLIX C300电源站？ 
- 🌍 全球可用
- ⚡ 288Wh容量，300W最大输出功率，280W最大充电功率
- 🔌 通过三条USB-C充电线为12V双臂、底座和树莓派提供全容量电力——消除复杂接线
- 🔋 卓越的电池寿命: 正常使用12+小时，密集操作8小时，1小时完全充电
- 💡 集成照明用于夜间操作
- ☀️ 可选太阳能板安装，提供持续电力
- 🎒 多功能且可拆卸——可兼作紧急备用电源或露营电源

    </td>
  </tr>
</table>


即使你不积极使用机器人，这两种产品在日常使用中仍然很有价值。

---

## 💻 软件介绍 💻
以下是如何控制机器人并使其智能化：

### 🕹️ 基本控制

- **关节**(电机角度)控制 → 主从臂控制

- **末端执行器姿态**控制 → VR远程控制
  
> [!NOTE]
> 对于第一个版本，我们主要关注硬件。LeRobot代码保持不变。你可以通过将一个臂连接到树莓派，另一个连接到桌面进行远程控制来重现Demo 0.1.0。**XLeRobot的LeRobot代码**将很快作为我们的首要任务进行更新。

### 🧠 通向通用具身机器智能的路径(待办)

### 🔈广告:
- **我们的实验室**: [Rice RobotPI Lab](https://robotpilab.github.io/)
    - 我们的愿景包括使用[**时间中的笼罩**](https://robotpilab.github.io/publication/caging/)和**漏斗式操作**方法，在不完美的现实世界条件下实现稳健的物体操作——包括感知噪声、网络延迟和[接触丰富](https://robotpilab.github.io/publication/collision-inclusive-manipulation/)环境。
- **模拟平台**(我个人偏好): [Maniskill](https://www.maniskill.ai/)
    - 🚀快速GPU加速用于并行模拟
    - 🎨通过光线追踪实现美丽的逼真视觉效果
    - 🪶轻量级、一致且用户友好(相比Isaac Lab，我个人观点)
    - 🤖支持[多种机器人](https://maniskill.readthedocs.io/en/latest/software/index.html)(包括[SO100臂](https://x.com/Stone_Tao/status/1910101218241978537))
    - 我自己玩出来的一个截屏：
    - 6dc9d8459f6809dc04d178e68e63c6a

---
## 未来计划

### 硬件
<table>
  <tr>
    <td>
      
**紧急**

- 🔧 添加两种臂底座选项：夹持式(当前)或螺钉安装式
- 🛠️ 添加与宜家推车金属网格完全兼容的连接板
    </td>
    </tr>
    <tr>
    <td>
    
**近期**

- 📸 在头部添加RealSense深度相机，补充手部RGB相机，实现精确环境感知
- 🔦 添加激光雷达和SLAM功能，实现类似Roomba的家庭导航
- 👆 基本触觉感应
    </td>
  </tr>
</table>

> [!NOTE]
> 虽然更高级的升级完全可能(如切换到Jetson处理器、升级底盘或使用更好的电机)，但这些会与本项目的核心使命相矛盾：**创建世界上最经济实惠、易于安装、即插即用的通用机器人开源平台**。但这些升级可以在未来作为可选附加组件列出，而不是主要方向。

### 软件

(软件更新也将取决于LeRobot社区的发展)
<table>
  <tr>
    <td>
      
**紧急**

- ⚙️ 基本控制算法
- 🎮 优化的末端执行器控制
- 🎲 Maniskill模拟环境
- 🕶️ Quest3 VR控制和远程操作
- 🤖 使用Lerobot代码库中现有VLA模型的简单任务
    </td>
    </tr>
    <tr>
    <td>
    
**近期**

- 🎯 基于AprilTag的精确校准
- 🗺️ 自主导航
- 🌐 数字孪生对齐，用于sim2real应用
- 🧠 世界模型和基于物理的稳健操作
- 💬 与MCP连接，直接利用LLMs
    </td>
  </tr>
</table>

---

## 🎯 XLeRobot适合谁？

- 🚀 **初创公司和实验室**: 使用世界上最便宜的模块化平台更快地构建原型
- 👩🔬 **自研人员**: 在不破产的情况下实验具身AI 💸
- 🎓 **教育英雄**:
  - 高中教师: 将前沿机器人技术带入STEM课堂 🧪
  - 大学教授: 机器人/AI课程的经济实惠平台 📚
  - 学生: 从初学者到研究人员 🎒→🎓
- 🤖 **DIY爱好者**: 完美适合室内项目 - 植物护理、递送机器人、家庭自动化 🌱📦
---

## 局限性

(要啥自行车？)

- 🔒 固定高度——添加稳定的升降平台将显著增加成本和组装难度
- 📏 与Aloha相比工作空间较小——虽然我们最大化了SO100的工作空间，但手臂有尺寸限制，不过XLeRobot仍能有效处理大多数任务
- ⚖️ 单臂负载能力有限——这就是为什么我们使用宜家推车
- 🛒 底座移动精度可能受到宜家推车轮子的影响——这可以通过闭环反馈控制解决
  
综合考虑——成本、社区支持、组装便捷性和实用性——XLeRobot脱颖而出，成为室内应用最具吸引力的低成本机器人之一！

---

## 主要贡献者

目前只有[我](https://vector-wangel.github.io/)。将来当更多人加入这个开源项目时，一定会更新这个列表。他们也将被添加到引用列表中作为作者之一。

这只是金字塔中的一小块砖，由[LeRobot](https://github.com/huggingface/lerobot)、[SO-100](https://github.com/TheRobotStudio/SO-ARM100)、[Lekiwi](https://github.com/SIGRobotics-UIUC/LeKiwi)和[Bambot](https://github.com/timqian/bambot)共同实现。感谢这些详细且专业项目背后所有才华横溢的贡献者。

期待与任何有兴趣为该项目做出贡献的人合作！

> [!NOTE]
> 目前忙于论文截稿日期，将从2025年7月开始公开寻求合作和投资。

与Anker或宜家没有关联(但我们喜欢瑞典肉丸！🍝)

---

## 引用

如果您愿意，可以使用以下方式引用本工作：

```bibtex
@misc{wang2025xlerobot,
    author = {Wang, Gaotian},
    title = {XLeRobot: A Practical Low-cost Household Dual-Arm Mobile Robot Design for General Manipulation},
    howpublished = "\url{https://github.com/Vector-Wangel/XLeRobot}",
    year = {2025}
}
```
未来一定会添加更多作者(如LeRobot和Lekiwi的开发者，在我亲自与他们确认后)。

---

## 🪧 免责声明 🪧
尽管我个人认为XLeRobot应该是目前物理意义上的安全系数最高的机器人之一了，但是：
> [!NOTE]
> 如果您基于此仓库构建XLeRobot，您将对其对您或他人造成的所有财产，身体和精神损害负全部责任。

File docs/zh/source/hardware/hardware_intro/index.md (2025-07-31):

## 🛠️ 硬件介绍 🛠️

**XLeRobot** = Lekiwi + 1x SO-100/SO-101 手臂 + **宜家RÅSKOG推车** + **Anker电池**

= 2x SO-100/SO-101 手臂 + 3x 全向轮 + 树莓派 + **宜家RÅSKOG推车** + **Anker电池**

#### 📜基本规格

- **重量**📏: ~12kg。成人可轻松抬起。
- **工作空间**🦾:
    - 高度范围: 距地面~0.5m-1.25m
    - 宽度范围: 距推车边缘~0.36m。
    - 能够完成许多家庭任务。
- **电池**🔋:
    - 300W最大输出: 足以为12V版本双臂 + lekiwi底座 + 树莓派(~180W最大)供电
    - 288Wh容量: 通常可运行10小时以上
    - 280W最大输入: 1小时即可充满
    - 可选太阳能板☀: 用于无限充电

> 所有计算都由你的PC处理——树莓派仅通过WiFi管理数据通信
>

#### 为什么选择宜家RÅSKOG推车？

- 🌎 全球可用，设计标准化
- 💰 经济实惠
- 🏗️ 结构简单但坚固
- 🔧 金属网格底部便于组件安装
- 📦 完美适合存储和运输
- 📏 理想高度适合常见家庭表面——从炉灶到咖啡桌
- 📏 紧凑的占地面积几乎适合任何房间(感谢宜家的周到设计)

#### 为什么选择Anker SOLIX C300电源站？

- 🌍 全球可用
- ⚡ 288Wh容量，300W最大输出功率，280W最大充电功率
- 🔌 通过三条USB-C充电线为12V双臂、底座和树莓派提供全容量电力——消除复杂接线
- 🔋 卓越的电池寿命: 正常使用12+小时，密集操作8小时，1小时完全充电
- 💡 集成照明用于夜间操作
- ☀️ 可选太阳能板安装，提供持续电力
- 🎒 多功能且可拆卸——可兼作紧急备用电源或露营电源

即使你不积极使用机器人，这两种产品在日常使用中仍然很有价值。

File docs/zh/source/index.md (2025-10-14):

# XLeRobot 

    

<!-- [![en](https://img.shields.io/badge/lang-en-blue.svg)](..)
[![中文](https://img.shields.io/badge/lang-中文-brown.svg)](README_CN.md)

<div class="lang-switch">
  <a onclick="switchLang('en')" class="active">
    <img src="https://img.shields.io/badge/lang-en-blue.svg" alt="English" />
  </a>
  <a onclick="switchLang('zh')">
    <img src="https://img.shields.io/badge/lang-中文-brown.svg" alt="中文" />
  </a>
</div>

<div class="lang-en">
[English content...]
</div>

<div class="lang-zh">
[Chinese content...]
</div> -->



## 介绍

**🚀 让具身AI走向全世界每个家庭！比iPhone还便宜📱！**

**⏰ <4小时总组装时间**

*站在巨人的肩膀上: [LeRobot](https://github.com/huggingface/lerobot), [SO-100/SO-101](https://github.com/TheRobotStudio/SO-ARM100), [Lekiwi](https://github.com/SIGRobotics-UIUC/LeKiwi), [Bambot](https://github.com/timqian/bambot)*

---

<video width="100%" controls>
  <source src="https://vector-wangel.github.io/XLeRobot-assets/videos/Real_demos/xlerobot030.mp4" type="video/mp4">
  Your browser does not support the video tag.
</video>

## 📰 新闻 
- 2025-09-22: **硬件组装教程视频** 发布于 [Youtube](https://www.youtube.com/watch?v=upB1CEFeOlk) 和 [Bilibili](https://www.bilibili.com/video/BV1AGWFzUEJf/). 感谢 WOWROBO 费心制作!
- 2025-09-09: **面向开发者的组装套件 (不包括电池和宜家推车) 正式上架** [中国 (淘宝) **3699￥**](https://e.tb.cn/h.SZFbBgZABZ8zRPe?tk=ba514rTBRjQ) 和 [全球 **579\$**](https://shop.wowrobo.com/products/xlerobot-dual-arm-mobile-household-robot-kit?variant=47297659961561). _(与**Wowrobo**合作, Huggingface SO101 手臂官方合作商之一, 已在全球范围卖出 5千+ SO101 手臂，用户反馈好)_
  
  - 售卖套件仅为项目推广，我本人不从中获利，并要求wowrobo以尽可能低价售卖.
  - 组装套件仅面向开发者，非消费级产品，请详细阅读文档和repo，确认目前可用的代码和教程后再购买.
- 2025-09-09: 作为导师团队之一参与由英伟达，Huggingface，SEEED联合举办的[具身智能家庭机器人黑客松](https://www.seeedstudio.com/embodied-ai-worldwide-hackathon-home-robot.html) (10.18-19深圳，10.25–26, 湾区)!.
- 

- 2025-08-30: XLeRobot 0.3.0 发布，最终外观完善和家庭杂务展示演示。

- 2025-07-30: [控制XLeRobot在真实环境中](https://xlerobot.readthedocs.io/en/latest/software/index.html) 使用**键盘/Xbox/Switch joycon**（蓝牙，无需wifi，0延迟）。
- rea

- 2025-07-08: [**Maniskill仿真**](https://xlerobot.readthedocs.io/en/latest/simulation/index.html) 支持URDF、控制脚本（支持Quest3 VR、键盘、Xbox、Switch Joycon）。支持多种传感器（深度、分割、触觉等），RL/IL/VLA环境。15分钟快速上手。
-  vr

- 2025-07-01: [**文档**网站](https://xlerobot.readthedocs.io/en/latest/index.html) 上线，提供更有序的教程、演示和资源。

- 2025-06-13: [**XLeRobot 0.2.0**](https://xlerobot.readthedocs.io) 硬件设置完全具备家务任务能力，成本660美元。

---
## 成本

| 价格（自己购买零件） | 美国 | 欧盟 | 中国 | 印度 |
| --- | --- | --- | --- | --- |
| **基础版** (使用自己的笔记本电脑，单RGB头部摄像头) | **~$660** | **~€680** | **~¥3999** | **~₹87000** |
| ↑ 立体双RGB头部摄像头 | +$30 | +€30 | +¥199 | +₹6550 |
| + 树莓派 | +$79 | +€79 | +¥399 | +₹7999 |
| ↑ RealSense RGBD头部摄像头 | +$220 | +€230 | +¥1499 | +₹35726 |

组装套件即将开售，敬请期待！

## 🌟 为什么选择XLeRobot？ 🌟



**XLeRobot = XL + LeRobot**

### 为什么选择"LeRobot"核心？

- **廉价材料** 💴: 90%的3D打印组件，配合经济实惠的电机和电子元件。
- **简易组装** 🔨: 67分钟即可组装2个SO101手臂并配置电机。
- **即插即用** 🧩: 通过简单的pip安装和几行代码让机器人运行起来。
- **蓬勃发展的LeRobot社区** 🌍:
世界上最大的低成本机器人社区，特色包括
    - 多个[最先进的预训练AI模型🧠](https://huggingface.co/lerobot)、数据集📊和工具🔨，随时可以部署。
    - 7000+聪明才智的头脑进行头脑风暴和讨论🧑‍🤝‍🧑。

### 为什么需要"XL"增强？



- 🏠 该领域/市场缺乏价格合理、稳定的双臂家用机器人，能够与LeRobot的简易组装相匹配。
- 🖨️ 传统3D打印底盘耐久性、稳定性和负载能力有限——使其不适合日常使用。
- ⚡ DIY移动机器人面临电源供应挑战，导致复杂的接线设置。

### 整体优势

- **经济实惠** 💴: 完整构建成本4000￥，或者从现有SO101Arm和Lekiwi升级仅需不到1500￥。
- **轻松升级** ⏫ 从**Lekiwi**和**SO-100/SO-101**
    - 硬件：无需更改电机ID或硬件修改
    - 软件：与桌面单臂/双臂设置相同——直接从SO-100/SO-101手臂转移您训练好的策略
- **实用可靠** 💪: 执行许多日常任务，可与市场上$30,000的闭源机器人相媲美。
    - 更多任务在[**Huggingface LeRobot全球黑客马拉松**](https://huggingface.co/spaces/LeRobot-worldwide-hackathon/all-winners)中展示。
    - **注意**：目前不适用于手内灵巧操作🤹、重物提升(每臂超过1kg)🏋️或高度动态运动(接球)🏃
- **丰富的开源资源** 📕
    - LeRobot的即插即用代码🧩和广泛的AI模型库🧠
    - 由活跃、不断增长的贡献者社区支持🧑‍🤝‍🧑
- **⚠️安全始终重要⚠️**: XLeRobot具有固有的物理硬件限制(低扭矩电机、短臂长、轮式基础)，使其**物理上**几乎不可能伤害人类，同时仍然保持执行许多家庭任务的能力。

---

## 🎯 XLeRobot适合谁？

- 🚀 **初创公司和实验室**: 使用世界上最便宜的模块化平台更快地构建原型
- 👩🔬 **自研人员**: 在不破产的情况下实验具身AI 💸
- 🎓 **教育英雄**:
    - 高中教师: 将前沿机器人技术带入STEM课堂 🧪
    - 大学教授: 机器人/AI课程的经济实惠平台 📚
    - 学生: 从初学者到研究人员 🎒→🎓
- 🤖 **DIY爱好者**: 完美适合室内项目 - 植物护理、递送机器人、家庭自动化 🌱📦

---

## 局限性

(嘿，这个价格，还要什么自行车？)

- 🔒 固定高度——添加稳定的升降平台将显著增加成本和组装难度
- 📏 与Aloha相比工作空间较小——虽然我们最大化了SO101的工作空间，但手臂有尺寸限制(~40cm reach)，不过XLeRobot仍能有效处理大多数任务
- ⚖️ 单臂负载能力有限(600~1000g)

综合考虑——成本、社区支持、组装便捷性和实用性——XLeRobot脱颖而出，成为室内应用最具吸引力的低成本机器人之一！

---

## 贡献

**👋 想要贡献？**
请参考[CONTRIBUTING.md](CONTRIBUTING.md)了解如何参与！

**主要贡献者**

- [Gaotian/Vector Wang](https://vector-wangel.github.io/)(我自己)
- Zhuoyi Lu: RL sim2real部署，真实机器人遥操作(Xbox, VR, Joycon)
- Nicole Yue: 文档网站设置
- Yuesong Wang: Mujoco仿真资源

这只是金字塔中的一小块砖，由[LeRobot](https://github.com/huggingface/lerobot)、[SO-100](https://github.com/TheRobotStudio/SO-ARM100)、[Lekiwi](https://github.com/SIGRobotics-UIUC/LeKiwi)和[Bambot](https://github.com/timqian/bambot)共同实现。感谢这些详细且专业项目背后所有才华横溢的贡献者。

期待与任何有兴趣为该项目做出贡献的人合作！

---

## 引用

如果您愿意，可以使用以下方式引用本工作：

```
@misc{wang2025xlerobot,
    author = {Wang, Gaotian and Lu, Zhuoyi},
    title = {XLeRobot: A Practical Low-cost Household Dual-Arm Mobile Robot Design for General Manipulation},
    howpublished = "\\url{<https://github.com/Vector-Wangel/XLeRobot>}",
    year = {2025}
}

```

---

## 🪧 免责声明 🪧

> 如果您基于此仓库构建、购买或开发XLeRobot，您将对其对您或他人造成的所有物理和精神损害负全部责任。
>



---

```{toctree}
:maxdepth: 1
hardware/index
simulation/index
software/index
demos/index
relatedworks/index
```

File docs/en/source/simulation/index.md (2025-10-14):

# Simulation

##### [👋 Get Started](getting_started/index)

- [A short technical blog](https://vectorwang.notion.site/Analytical-IK-for-SO101-20abb280f59380d288bcdd398ffbfab1) for analytical IK introduction.

- A detailed [**Step-by-step Installation Guide**](getting_started/index) that can get you started to replicate this demo in 10 min.

- URDF files, maniskill robot agent scripts, joint/EE control scripts.

##### [👀 VR Control](getting_started/vr_sim)

<video width="100%" style="max-width: 100%;" controls>
  <source src="https://vector-wangel.github.io/XLeRobot-assets/videos/Sim_demos/XLeRobot_0_2_3.mp4" type="video/mp4">
  Your browser does not support the video tag.
</video>

##### [🔩 More Scenes](getting_started/simdemos)

<video width="100%" style="max-width: 100%;" controls>
  <source src="https://vector-wangel.github.io/XLeRobot-assets/videos/Sim_demos/XLeRobot_0_1_5.mp4" type="video/mp4">
  Your browser does not support the video tag.
</video>

```{toctree}
getting_started/index
getting_started/vr_sim
getting_started/simdemos
```

<!-- ```{toctree}
:maxdepth: 1

control/index
table_top_gripper/index
quadruped/index
humanoid/index
mobile_manipulation/index
dextrous/index
digital_twins/index
drawing/index
external/index
``` -->

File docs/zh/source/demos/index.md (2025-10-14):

# 演示

### 总体

<video width="100%" controls>
  <source src="https://vector-wangel.github.io/XLeRobot-assets/videos/Real_demos/xlerobot030.mp4" type="video/mp4">
  Your browser does not support the video tag.
</video>

### VR控制

<video width="100%" controls>
  <source src="https://vector-wangel.github.io/XLeRobot-assets/videos/Real_demos/XLeVR.mp4" type="video/mp4">
  Your browser does not support the video tag.
</video>

### 自主强化学习

<video width="100%" controls>
  <source src="https://vector-wangel.github.io/XLeRobot-assets/videos/Real_demos/sim2real_2.mp4" type="video/mp4">
  Your browser does not support the video tag.
</video>

### 基于YOLO的物体跟踪

<video width="100%" controls>
  <source src="https://vector-wangel.github.io/XLeRobot-assets/videos/Real_demos/yolo.mp4" type="video/mp4">
  Your browser does not support the video tag.
</video>

### 仿真

#### 仿真中的VR控制

<video width="100%" controls>
  <source src="https://vector-wangel.github.io/XLeRobot-assets/videos/Sim_demos/XLeRobot_0_2_3.mp4" type="video/mp4">
  Your browser does not support the video tag.
</video>

#### 场景展示
<video width="100%" controls>
  <source src="https://vector-wangel.github.io/XLeRobot-assets/videos/Sim_demos/XLeRobot_0_1_5.mp4" type="video/mp4">
  Your browser does not support the video tag.
</video>

### 动力学

<video width="100%" controls>
  <source src="https://vector-wangel.github.io/XLeRobot-assets/videos/Real_demos/Dynamic.mp4" type="video/mp4">
  Your browser does not support the video tag.
</video>

由Mitchell Chen制作的演示

### 第一个演示0.1.0 (XLeRobot的起点)

<video width="100%" style="max-width: 100%;" controls>
  <source src="https://github.com/user-attachments/assets/98312e30-9a5d-41a1-a6ce-ef163c3abfd5" type="video/mp4">
  Your browser does not support the video tag.
</video>

### 社区演示

欢迎每个人在这里贡献！您可以通过修改[此文件](https://github.com/Vector-Wangel/XLeRobot/edit/main/docs/en/source/demos/index.md)并在github上提交pull request直接在此处添加您的演示。

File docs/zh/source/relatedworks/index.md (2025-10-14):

# 相关工作

🤗这里收录了所有我发现有趣、有意义且对XLeRobot未来应用有潜力的工作，包括机器人研究和LeRobot社区的作品。

## 博客

[SO101解析逆运动学](https://vectorwang.notion.site/Analytical-IK-for-SO101-20abb280f59380d288bcdd398ffbfab1?pvs=25)

### 👀 感知 

#### DRAWER: 便捷的关节式Real2Sim

[DRAWER: 具有环境真实感的数字重建和关节运动](https://xiahongchi.github.io/DRAWER/)

<video width="100%" controls>
  <source src="https://vector-wangel.github.io/XLeRobot-assets/videos/Other_works/DRAWER.mp4" type="video/mp4">
  Your browser does not support the video tag.
</video>

#### CoTracker

[CoTracker3: 通过伪标记真实视频实现更简单更好的点跟踪](https://cotracker3.github.io/)

### 🧠 高级任务规划 

#### VJEPA-2: 自监督基础世界模型

[介绍V-JEPA 2](https://ai.meta.com/vjepa/)

<video width="100%" controls>
  <source src="https://vector-wangel.github.io/XLeRobot-assets/videos/Other_works/VJEPA2.mp4" type="video/mp4">
  Your browser does not support the video tag.
</video>

### 🙌 低级运动控制

#### HIL-SERL: 当前强化学习SOTA(个人观点)

[HIL-SERL: 通过人在环强化学习实现精确灵巧的机器人操作](https://hil-serl.github.io/)

[HIL-SERL LeRobot训练指南](https://huggingface.co/docs/lerobot/hilserl)

#### 时间中的笼罩: 鲁棒物体操作的规划框架

[时间中的笼罩: 不确定性和有限机器人感知下的鲁棒物体操作框架](https://journals.sagepub.com/doi/pdf/10.1177/02783649251343926)

<video width="100%" controls>
  <source src="https://vector-wangel.github.io/XLeRobot-assets/videos/Other_works/CIT.mp4" type="video/mp4">
  Your browser does not support the video tag.
</video>

### 👨‍🔧 硬件

#### 3D Vitac: 低成本Velostat触觉传感器

[3D-ViTac: 通过视觉-触觉感知学习精细操作](https://binghao-huang.github.io/3D-ViTac/)

<video width="100%" controls>
  <source src="https://vector-wangel.github.io/XLeRobot-assets/videos/Other_works/3D-Vitac.mp4" type="video/mp4">
  Your browser does not support the video tag.
</video>

#### E-flesh: 低成本磁性触觉传感器

[eFlesh: 使用切割单元微结构的高度可定制磁性触觉感知](https://e-flesh.com)

<video width="100%" controls>
  <source src="https://vector-wangel.github.io/XLeRobot-assets/videos/Other_works/eflesh.mp4" type="video/mp4">
  Your browser does not support the video tag.
</video>

#### BACH手: 带驱动主动表面手指 

[带式增强柔顺手](https://yuanshenli.com/bach.html)

BACH hand demo

### 💻 仿真

#### Maniskill: 轻量级GPU加速操作专用仿真器

[ManiSkill — ManiSkill 3.0.0b21 文档](https://maniskill.readthedocs.io/en/latest/)

#### RoboTwin: 基于Maniskill的大型双臂操作基准

[RoboTwin 2.0: 用于鲁棒双臂机器人操作的具有强域随机化的可扩展数据生成器和基准](https://robotwin-platform.github.io/)

### 🧑‍🍳 开发中

#### Bambot: 基于网页的控制面板 

[Tim Qian的BamBot](https://bambot.org/)

[BamBot Feetech舵机控制面板 - feetech.js](http://bambot.org/feetech.js)

#### 模型上下文协议 (MCP)

- [在Lerobot SO101手臂上使用MCP](https://github.com/IliaLarchenko/robot_MCP)
- [MCP官方网站](https://modelcontextprotocol.io/introduction)

#### 3D重建

[Hunyuan3D-2](https://huggingface.co/spaces/tencent/Hunyuan3D-2)

#### Maniskill Sim2real强化学习

[Stone Tao的lerobot-sim2real](https://github.com/StoneT2000/lerobot-sim2real)

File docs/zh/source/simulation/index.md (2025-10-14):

# 仿真

##### [👋 开始使用](getting_started/index)

- [解析逆运动学介绍的简短技术博客](https://vectorwang.notion.site/Analytical-IK-for-SO101-20abb280f59380d288bcdd398ffbfab1)。

- 详细的[**逐步安装指南**](getting_started/index)，让您能在10分钟内开始复制这个演示。

- URDF文件、maniskill机器人代理脚本、关节/末端执行器控制脚本。

##### [👀 VR控制](getting_started/vr_sim)

<video width="100%" style="max-width: 100%;" controls>
  <source src="https://vector-wangel.github.io/XLeRobot-assets/videos/Sim_demos/XLeRobot_0_2_3.mp4" type="video/mp4">
  Your browser does not support the video tag.
</video>

##### [🔩 更多场景](getting_started/simdemos)

<video width="100%" style="max-width: 100%;" controls>
  <source src="https://vector-wangel.github.io/XLeRobot-assets/videos/Sim_demos/XLeRobot_0_1_5.mp4" type="video/mp4">
  Your browser does not support the video tag.
</video>

```{toctree}
getting_started/index
getting_started/vr_sim
getting_started/simdemos
```

<!-- ```{toctree}
:maxdepth: 1

control/index
table_top_gripper/index
quadruped/index
humanoid/index
mobile_manipulation/index
dextrous/index
digital_twins/index
drawing/index
external/index
``` -->

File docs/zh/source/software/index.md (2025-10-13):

<!-- THIS IS ALL GENERATED DOCUMENTATION via generate_robot_docs.py. DO NOT MODIFY THIS FILE DIRECTLY. -->

# 软件

这里我们将展示如何在lerobot框架下运行XLeRobot。

### [安装LeRobot 🤗 并移动XLeRobot文件](getting_started/install.md)

### 快速指南

```{note}
如果您之前没有使用过lerobot SO101手臂，建议先测试单臂设置遥操作并先熟悉一段时间。
```

1. **选择控制方法**: 关节控制(示例0)用于基本电机测试，末端执行器控制用于遥操作(示例1 & 6)
2. **高级功能**: 尝试双臂控制(示例2)或基于视觉的控制(示例3)进行更复杂的任务
3. **完整系统**: 使用键盘(示例4)、Xbox控制器(示例5)或Switch Joycon(示例7)进行完整的XLeRobot遥操作

所有示例脚本都位于[`software/examples/`](https://github.com/Vector-Wangel/XLeRobot/tree/main/software/examples)目录中，在正确设置和校准后可以直接运行。某些示例需要额外校准以确保性能。

```{note}
对于XLeRobot的基础版本，您不需要树莓派。只需使用您的笔记本电脑，如果您想使用完整系统，可以将其放在宜家推车中。
```

### [SO100/SO101手臂示例](getting_started/SO101.md)

### [XLeRobot遥操作](getting_started/XLeRobot_teleop.md)

### [强化学习(RL) & VLA](getting_started/RL_VLA.md)

## [树莓派设置](getting_started/raspberry_pi_setup.md)

```{toctree}
getting_started/install
getting_started/SO101
getting_started/XLeRobot_teleop
getting_started/RL_VLA
getting_started/raspberry_pi_setup.md
```

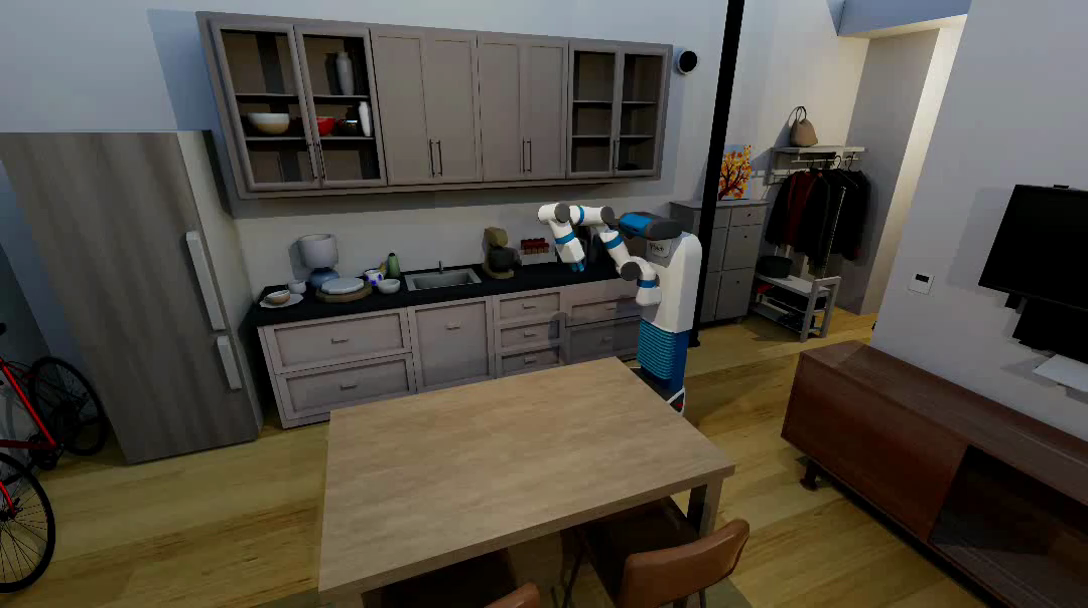
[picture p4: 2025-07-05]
docs/en/source/_static/env_thumbnails/ManiSkill-HAB_rt_poster.png

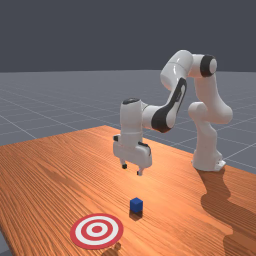
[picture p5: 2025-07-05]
docs/zh/source/_static/env_thumbnails/PushCube-v1_rt_thumb_first.png

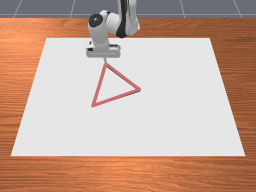
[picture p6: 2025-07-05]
docs/en/source/_static/env_thumbnails/DrawTriangle-v1_rt_thumb_last.png

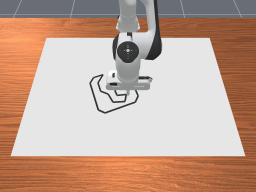
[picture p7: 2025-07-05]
docs/en/source/_static/env_thumbnails/DrawSVG-v1_rt_thumb_first.png

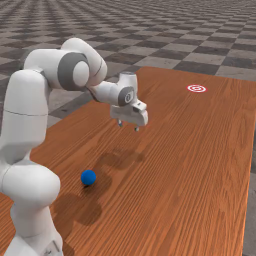
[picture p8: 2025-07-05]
docs/en/source/_static/env_thumbnails/RollBall-v1_rt_thumb_first.png

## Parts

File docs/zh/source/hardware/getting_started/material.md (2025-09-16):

# 🛒 **材料清单**

## 💵 总成本 

```{note}
不包括3D打印、工具、运输和税费的成本。
```

| 价格 | 美国 | 欧盟 | 中国 | 印度 |
| --- | --- | --- | --- | --- |
| **基础版** (使用自己的笔记本电脑，单RGB头部摄像头) | **~$660** | **~€680** | **~¥3999** | **~₹87000** |
| ↑ 立体双RGB头部摄像头 | +$30 | +€30 | +¥199 | +₹6550 |
| + 树莓派 | +$79 | +€79 | +¥399 | +₹7999 |
| ↑ RealSense RGBD头部摄像头 | +$220 | +€230 | +¥1499 | +₹35726 |

e65bf20604df6c937d00115f2ed7bc2

```{tip}
你可以从[Wowrobo](https://shop.wowrobo.com/products/so-arm101-diy-kit-assembled-version-1)购买SO101手臂的打印零件或预组装套件。SO101手臂需要大约1.5小时来组装两个手臂。
```

```{note}
如果你已经有SO101手臂或Lekiwi，请有选择地参考此BOM。我们建议同时查看其他两个仓库(SO100、Lekiwi)，可能有更优惠的价格选项。
```

## 🔨 组装工具 

如果你已经有这些工具，可以跳过这一部分：

| 零件 | 数量 | 单价 (美国) | 购买 (美国) | 单价 (欧盟) | 购买 (欧盟) | 单价 (中国) | 购买 (中国) | 单价 (印度) | 购买 (印度) |
| --- | --- | --- | --- | --- | --- | --- | --- | --- | --- |
| M3螺丝和螺母套装 (配L型螺丝刀) | 1 | $14.99 | [Amazon](https://a.co/d/4NfBpNS) | €23.5 | [Amazon](https://www.amazon.fr/Cylindrique-Inoxydable-M2-Socket-Assortiment/dp/B09Y8WYFWD/) | ¥40 | [Taobao](https://item.taobao.com/item.htm?id=614760389801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) | ₹1699 | [Amazon India](https://www.amazon.in/Epi-Torque-Epic-Torque-Doityourself-Tensile/dp/B08F5J4YS6/) |
| 齐头钳 | 1 | $6.99 | [Amazon](https://a.co/d/61KlrZp) | €23.5 | [Amazon](https://www.amazon.fr/Cylindrique-Inoxydable-M2-Socket-Assortiment/dp/B09Y8WYFWD/) | ¥5.8 | [Taobao](https://item.taobao.com/item.htm?id=706039364576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) | ₹297 | [Amazon India](https://www.amazon.in/Homdum-Electronic-Jewellery-Electric-Strippers/dp/B09SZH1JQ2) |
| 螺丝刀套装 | 1 | $6 | [Amazon](https://www.amazon.com/Precision-Phillips-Screwdriver-Electronics-Computer/dp/B0DB227RTH) | €10 | [Amazon](https://www.amazon.fr/dp/B08ZXVMVYD/) | ￥20 | [Taobao](https://e.tb.cn/h.6ReL0wwgtPuSmNV?tk=3rLDV10AVtr) | ₹448 | [Amazon India](https://www.amazon.in/Zaptec-Magnetic-Screwdriver-Suitable-Electronics/dp/B0CN3GTCT6/) |
- 使用齐头钳切割金属网格进行线缆布线。
- 这个工具清单只是参考——你可以使用任何能完成任务的工具，主要用于驱动内六角和十字头螺丝。

## ⏫ 主要零件

| 零件 | 数量 | 单价 (美国) | 购买 (美国) | 单价 (欧盟) | 购买 (欧盟) | 单价 (中国) | 购买 (中国) | 单价 (印度) | 购买 (印度) |
| --- | --- | --- | --- | --- | --- | --- | --- | --- | --- |
| STS3215舵机 (12V) | 17 | $14 | [Wowrobo](https://shop.wowrobo.com/products/feetech-sts3215-servo-12v-30kg-high-torque-servo-for-so-arm100) | €16 | [Aliexpress](https://www.aliexpress.com/item/1005009271910382.html) | ￥97 | [TaoBao](https://item.taobao.com/item.htm?id=712179366565&skuId=5268252241438) | ₹2097 | [Robu.in](https://robu.in/product/waveshare-30kg-serial-bus-servo/) |
| 宜家RÅSKOG推车 | 1 | $39.99 | [IKEA](https://www.ikea.com/us/en/p/raskog-utility-cart-black-40582181/#content) | €39.99 | [IKEA](https://www.ikea.com/nl/en/p/raskog-trolley-white-30586783/) | ￥249 | [IKEA](https://www.ikea.cn/cn/zh/p/raskog-la-si-ke-shou-tui-che-bai-se-70376721/) | ₹2600 | [Amazon India](https://www.amazon.in/Ikea-R%C3%85SKOG-Trolley-0-35x0-45-Cotton/dp/B07SGJ2RSM) |
| Anker SOLIX C300电源站 | 1 | $179.99 | [Anker](https://www.ankersolix.com/products/c300-dc?variant=49702163972426&ref=naviMenu_pps) | €169.99 | [Anker](https://www.anker.com/eu-en/products/a17260z1?variant=44598991323326&ref=naviMenu_pps) | ￥899 | [Taobao](https://e.tb.cn/h.6PQRiymMOteAgrb?tk=m6L3V3frrfp) | ₹27899 | [Ubuy India](https://www.ubuy.co.in/product/M62UNA548-solix-c300-portable-power-station-outdoor-288wh-lifepo4-battery-300w-600w-surge-solar-generator-140w-two-way-fast-charging-f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) |
| 4英寸全向轮 | 3 | $9.99 | [VEX Robotics](https://www.vexrobotics.com/omni-wheels.html?srsltid=AfmBOorWdWT-FIiWSAbicYWSxqYr-d5X3CJSGxMkO33WO0thwlTn4DQu) | €24.5 | [RobotShop](https://eu.robotshop.com/products/100mm-omnidirectional-wheel-brass-bearing-rollers) | ￥135 | [PDD](https://mobile.yangkeduo.com/goods.html?ps=kKWPC7xuzw) | ₹4380 | [Robu.in](https://robu.in/product/100mm-double-aluminium-omni-wheel-bush-type-roller/) |
| 桌夹 4个 | 1 | $8.99 | [Amazon](https://www.amazon.com/TAODAN-Trigger-Ratchet-Woodworking-Processes/dp/B0DJNXF8WH?rps=1&sr=1-18) | ~€8 | [TODO](https://www.notion.so/Bill-of-Material-21abb280f59380f48e49e5c51df2b37f?pvs=21) | ￥9.2 | [TaoBao](https://detail.tmall.com/item.htm?id=801399113134&skuId=5633627126649) | ₹772 | [Amazon India](https://www.amazon.in/HASTHIP%C2%AE-Two-Way-Woodworking-Trigger-Jigsaw/dp/B0BDDHN238/) |



- XLeRobot为最大功率而设计，这就是为什么它只有12V版本。
- 17个电机 = 12个用于手臂 + 3个用于底座 + 2个用于头部。
- 任何支持两个 60W+ USB-C 快充的电池/充电宝/充电站都应该可以使用。以下是一些其他潜在选择（未经测试），这些品牌在美国和中国都应该可以买到。
  - [绿联 300W 48000mAh 充电宝](https://www.ugreen.com/products/ugreen-300w-48000mah-portable-charger-power-bank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)
  - [Anker 笔记本电脑充电宝 (25K, 165W)](https://www.anker.com/products/a1695-anker-power-bank-25000mah-165w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)
  - [AOHI 240W 笔记本电脑充电宝 27600mAh](https://a.co/d/aW8lNc2)

## 💻 电子元件

| 零件 | 数量 | 单价 (美国) | 购买 (美国) | 单价 (欧盟) | 购买 (欧盟) | 单价 (中国) | 购买 (中国) | 单价 (印度) | 购买 (印度) |
| --- | --- | --- | --- | --- | --- | --- | --- | --- | --- |
| 树莓派5 (4GB) | 1 | $60.00 | [Adafruit](https://www.adafruit.com/product/5812) | €57.00 | [Mouser](https://eu.mouser.com/ProductDetail/Raspberry-Pi/SC1111?qs=HoCaDK9Nz5fnLhlMNnKTiQ%3D%3D) | ￥410 | [Taobao](https://e.tb.cn/h.64IIvlisvAL15g8?tk=fdOVexkHECW) | [Robu.in](https://robu.in/product/raspberry-pi-5-model-4gb/) |
| 电机控制板 | 2 | $10.55 | [Amazon](https://www.amazon.com/Waveshare-Integrates-Control-Circuit-Supports/dp/B0CTMM4LWK/) | €12.00 | [Amazon](https://www.amazon.fr/Waveshare-Integrates-Control-Applicable-Integrate/dp/B0CJ6TP3TP) | ￥24 | [Taobao](https://e.tb.cn/h.64DOUpLpB5crVdH?tk=BSaTex9UHWj) | ₹4041 | [Amazon India](https://www.amazon.in/Wonrabai-Integrates-Control-Circuit-Supports/dp/B0D1R4SGFS/) |
| microSD卡 | 1 | $11.23 | [Amazon](https://www.amazon.com/SanDisk-Extreme-microSDXC-Memory-Adapter/dp/B09X7C7LL1/) | €10.00 | [Amazon](https://www.amazon.fr/Lexar-Carte-Micro-adaptateur-Smartphone/dp/B08XZ2KS1F) | ￥58 | [Taobao](https://e.tb.cn/h.64DMZzLz5h26s12?tk=eImPex96lCQ) | ₹739 | [Amazon India](https://www.amazon.in/SanDisk-Extreme-microSD-Smartphones-Action/dp/B0B2DDJGF8/) |
| USB-C转USB-A线 2根 | 1 | $8.99 | [Amazon](https://a.co/d/0mWsmhG) | €7 | [Amazon](https://www.amazon.fr/dp/B07BNF842T/) | ￥17 | [Taobao](https://e.tb.cn/h.64HOv24RLmYC4Yh?tk=AXpgexkDFd4) | ₹799 | [Amazon India](https://www.amazon.in/Powerline-Charging-Compatibility-Delivery-MacBook/dp/B07DD5YHMH) |
| USB-C线 2根 | 1 | $8.99 | [Amazon](https://a.co/d/f8hm4E2) | ~€7 | [TODO](https://www.notion.so/Bill-of-Material-21abb280f59380f48e49e5c51df2b37f?pvs=21) | ￥17 | [Taobao](https://detail.tmall.com/item.htm?id=562374737204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) | ₹899 | [Amazon India](https://www.amazon.in/Anker-Charging-MacBook-Galaxy-Charger/dp/B088NRLMPV/) |
| Anker USB集线器 | 1 | $15.99 | [Amazon](https://a.co/d/6tJW8lN) |  |  | ￥52 | [Taobao](https://e.tb.cn/h.hTEgXX1RlPY0lWL?tk=AKLz4a3uOsA) | ₹699 | [Amazon India](https://www.amazon.in/Anker-4-Port-Ultra-Extended-MacBook/dp/B07L32B9C2/) |
| 4英尺5264电线 | 1 | $21.99 | [Amazon](https://www.amazon.com/dp/B0D2W47V8V) | ~€20 | [TODO](https://www.notion.so/Bill-of-Material-21abb280f59380f48e49e5c51df2b37f?pvs=21) | ¥20 | [Taobao](https://e.tb.cn/h.6ZvsvUU7wlxTIqu?tk=mz7PeJUloea) 3P-1000mm和5264连接器 | ₹7209 | [Amazon India](https://www.amazon.in/Keszoox-Connector-Assortment-Compatible-Pre-Crimped/dp/B0DCYYWZT7) |
| Type C转DC线(12V) | 2 | $8.99 | [Amazon 12V](https://www.amazon.com/dp/B0CDBWHXDZ) | ~€8 | [TODO](https://www.notion.so/Bill-of-Material-21abb280f59380f48e49e5c51df2b37f?pvs=21) | ¥20 | [Taobao 12V](https://e.tb.cn/h.6ZvuOW01EmvvHq1?tk=nzvFeJUnyuB) | ₹659 | [Amazon India](https://www.amazon.in/Tobo-7-4x0-6MM-Flexible-Charging-TD-1125CC/dp/B0CQNWRZQ) |



- 在美国无法购买到现成的长5264电线——只有需要手动组装以延长长度的**连接器套件**(这很简单)。
- 2根USB-C转USB-A线将电机控制板连接到树莓派/PC
- USB-C线将树莓派连接到电池
- 两根Type-C转DC线(12V)将电机控制板连接到电源。

## 📷 传感器 

| 零件 | 数量 | 单价 (美国) | 购买 (美国) | 单价 (欧盟) | 购买 (欧盟) | 单价 (中国) | 购买 (中国) | 单价 (印度) | 购买 (印度) |
| --- | --- | --- | --- | --- | --- | --- | --- | --- | --- |
| 手部相机 | 2 | $12.98 | [Amazon](https://a.co/d/fXX2odP) | ~€10 | [TODO](https://www.notion.so/Bill-of-Material-21abb280f59380f48e49e5c51df2b37f?pvs=21) | ￥99 | [Taobao](https://item.taobao.com/item.htm?ft=t&id=860171734711) | ₹3278 | [Desert Cart](https://www.desertcart.in/products/612412428-innomaker-1080p-usb-2-0-uvc-camera-130-wide-angle) |
| 罗技C920 | 1 | $66 | [Amazon](https://a.co/d/gM8vei1) |  |  | ￥309 |[Taobao]( https://e.tb.cn/h.hjpjA9cw3DpgwQi?tk=DRu642dmCo8 ) | ₹8459 | [Amazon India](https://www.amazon.in/Logitech-C920-Pro-Webcam-Microphones/dp/B006JH8T3S/) |
| RealSense D415 (专业版可选) | 1 | $272 | [Intel](https://store.intelrealsense.com/buy-intel-realsense-depth-camera-d415.html) |  |  | ￥1950 |[Taobao](https://e.tb.cn/h.hTHju7zCMDMR84q?tk=z0WU4aXOKey)  | ₹35726 | [Robu.in](https://robu.in/product/intel-d415-realsense-depth-camera/) |



## 🧑‍🤝‍🧑 备选方案 

- **宜家推车**: 你可以使用非宜家的类似推车；但是，这可能需要对[3D打印零件](https://www.notion.so/vectorwang/3D_Models/3D_models_for_printing/XLeRobot_special/base_connector.stl)进行小幅调整。
- **电池**: 你可以使用**其他电池**，但要确保最大输出容量能够充分为2个手臂、3个轮子和一个树莓派(~160W)供电。
- **电子元件**: 你可以使用任何品牌的线缆(USB-C线必须是快充类型)、microSD卡和树莓派5，只要它们兼容。

## 🧩 可选附加组件 

- 🙌双臂主从关节控制: 额外的两个[SO100手臂套装](https://github.com/TheRobotStudio/SO-ARM100/tree/main)用于双臂主从关节控制
- ✊更好的抓握稳定性: [3M抓握胶带](https://www.amazon.com/gp/product/B0093CQPW8/ref=ppx_yo_dt_b_search_asin_title?ie=UTF8&psc=1) (来自[UMI抓握器规格](https://docs.google.com/document/d/1TPYwV9sNVPAi0ZlAupDMkXZ4CA1hsZx7YDMSmcEy6EU/edit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))
- 👀VR控制: Meta Quest 3 (或3S)
- 触觉传感器: E-flesh
- 更多附加组件和配件，请查看[SO100手臂仓库](https://github.com/TheRobotStudio/SO-ARM100/tree/main?tab=readme-ov-file#optional-hardware)

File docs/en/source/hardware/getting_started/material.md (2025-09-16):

# 🛒 **Bill of Material**

## 💵 Total Cost 

```{note}
Doesn't include cost of 3D printing, tools, shipping and taxes.
```

| Price | US | EU | CN | IN |
| --- | --- | --- | --- | --- |
| **Basic** (use your laptop, single RGB head cam) | **~$660** | **~€680** | **~¥3999** | **~₹87000** |
| ↑ Stereo dual-eye RGB head cam | +$30 | +€30 | +¥199 | +₹6550 |
| + RaspberryPi | +$79 | +€79 | +¥399 | +₹7999 |
| ↑ RealSense RGBD head cam | +$220 | +€230 | +¥1499 | +₹35726 |

e65bf20604df6c937d00115f2ed7bc2

```{tip}
You can purchase printed parts or pre-assembled kits from [Wowrobo](https://shop.wowrobo.com/products/so-arm101-diy-kit-assembled-version-1) for SO101 arms. The SO101 arms require about 1.5 hours assembly for two arms.
```

```{note}
If you already have SO101 arms or Lekiwi, refer to this BOM selectively. We recommend checking the other two repos (SO100, Lekiwi) as well for potentially better-priced options.
```

## 🔨 Assembly Tools 

Skip this section if you already have these tools:

| Part | Amount | Unit Cost (US) | Buy (US) | Unit Cost (EU) | Buy (EU) | Unit Cost (CN) | Buy (CN) | Unit Cost (IN) | Buy (IN) |
| --- | --- | --- | --- | --- | --- | --- | --- | --- | --- |
| M3 Screws and Nuts Set (come with the L-shape screw driver) | 1 | $14.99 | [Amazon](https://a.co/d/4NfBpNS) | €23.5 | [Amazon](https://www.amazon.fr/Cylindrique-Inoxydable-M2-Socket-Assortiment/dp/B09Y8WYFWD/) | ¥40 | [Taobao](https://item.taobao.com/item.htm?id=614760389801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) | ₹1699 | [Amazon India](https://www.amazon.in/Epi-Torque-Epic-Torque-Doityourself-Tensile/dp/B08F5J4YS6/) |
| Flush cutter | 1 | $6.99 | [Amazon](https://a.co/d/61KlrZp) | €23.5 | [Amazon](https://www.amazon.fr/Cylindrique-Inoxydable-M2-Socket-Assortiment/dp/B09Y8WYFWD/) | ¥5.8 | [Taobao](https://item.taobao.com/item.htm?id=706039364576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) | ₹297 | [Amazon India](https://www.amazon.in/Homdum-Electronic-Jewellery-Electric-Strippers/dp/B09SZH1JQ2) |
| Screwdriver Set | 1 | $6 | [Amazon](https://www.amazon.com/Precision-Phillips-Screwdriver-Electronics-Computer/dp/B0DB227RTH) | €10 | [Amazon](https://www.amazon.fr/dp/B08ZXVMVYD/) | ￥20 | [Taobao](https://e.tb.cn/h.6ReL0wwgtPuSmNV?tk=3rLDV10AVtr) | ₹448 | [Amazon India](https://www.amazon.in/Zaptec-Magnetic-Screwdriver-Suitable-Electronics/dp/B0CN3GTCT6/) |
- Use a flush cutter to cut the metal mesh for cable routing.
- This tool list is just a reference—you can use any tools that will accomplish the task, primarily for driving hex and cross-head screws.
- 9x M4x10 screws are also needed for wheels assembly. 

## ⏫ Feature Parts

| Part | Amount | Unit Cost (US) | Buy (US) | Unit Cost (EU) | Buy (EU) | Unit Cost (CN) | Buy (CN) | Unit Cost (IN) | Buy (IN) |
| --- | --- | --- | --- | --- | --- | --- | --- | --- | --- |
| STS3215 Servo (12V) | 17 | $14 | [Wowrobo](https://shop.wowrobo.com/products/feetech-sts3215-servo-12v-30kg-high-torque-servo-for-so-arm100) | €16 | [Aliexpress](https://www.aliexpress.com/item/1005009271910382.html) | ￥97 | [TaoBao](https://item.taobao.com/item.htm?id=712179366565&skuId=5268252241438) | ₹2097 | [Robu.in](https://robu.in/product/waveshare-30kg-serial-bus-servo/) |
| IKEA RÅSKOG Utility cart | 1 | $39.99 | [IKEA](https://www.ikea.com/us/en/p/raskog-utility-cart-black-40582181/#content) | €39.99 | [IKEA](https://www.ikea.com/nl/en/p/raskog-trolley-white-30586783/) | ￥249 | [IKEA](https://www.ikea.cn/cn/zh/p/raskog-la-si-ke-shou-tui-che-bai-se-70376721/) | ₹2600 | [Amazon India](https://www.amazon.in/Ikea-R%C3%85SKOG-Trolley-0-35x0-45-Cotton/dp/B07SGJ2RSM) |
| Anker SOLIX C300 Power Station | 1 | $179.99 | [Anker](https://www.ankersolix.com/products/c300-dc?variant=49702163972426&ref=naviMenu_pps) | €169.99 | [Anker](https://www.anker.com/eu-en/products/a17260z1?variant=44598991323326&ref=naviMenu_pps) | ￥899 | [Taobao](https://e.tb.cn/h.6PQRiymMOteAgrb?tk=m6L3V3frrfp) | ₹27899 | [Ubuy India](https://www.ubuy.co.in/product/M62UNA548-solix-c300-portable-power-station-outdoor-288wh-lifepo4-battery-300w-600w-surge-solar-generator-140w-two-way-fast-charging-f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) |
| 4" Omni wheels | 3 | $9.99 | [VEX Robotics](https://www.vexrobotics.com/omni-wheels.html?srsltid=AfmBOorWdWT-FIiWSAbicYWSxqYr-d5X3CJSGxMkO33WO0thwlTn4DQu) | €24.5 | [RobotShop](https://eu.robotshop.com/products/100mm-omnidirectional-wheel-brass-bearing-rollers) | ￥135 | [PDD](https://mobile.yangkeduo.com/goods.html?ps=kKWPC7xuzw) | ₹4380 | [Robu.in](https://robu.in/product/100mm-double-aluminium-omni-wheel-bush-type-roller/) |
| Table Clamp 4pcs | 1 | $8.99 | [Amazon](https://www.amazon.com/TAODAN-Trigger-Ratchet-Woodworking-Processes/dp/B0DJNXF8WH?rps=1&sr=1-18) | ~€8 | [TODO](https://www.notion.so/Bill-of-Material-21abb280f59380f48e49e5c51df2b37f?pvs=21) | ￥9.2 | [TaoBao](https://detail.tmall.com/item.htm?id=801399113134&skuId=5633627126649) | ₹772 | [Amazon India](https://www.amazon.in/HASTHIP%C2%AE-Two-Way-Woodworking-Trigger-Jigsaw/dp/B0BDDHN238/) |



- XLeRobot is designed to be practical, which is why it only comes in a 12V version. You can also purchase for [STS3250 servo](https://shop.wowrobo.com/products/feetech-sts3250-c002-servo-12v-50kg-1-345-servo) (1.5x torque, 3x price) for extreme performance.
- 17 motors = 12 for arms + 3 for base + 2 for head.
- Any battery/power bank/power station that supports two 60W+ USB-C fast charging should work. Here are some other potential options (not tested), these brands should be available both in US and China.
  - [UGREEN 300W 48000mAh Power Bank](https://www.ugreen.com/products/ugreen-300w-48000mah-portable-charger-power-bank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)
  - [Anker Laptop Power Bank (25K, 165W)](https://www.anker.com/products/a1695-anker-power-bank-25000mah-165w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)
  - [AOHI 240W Laptop Power Bank 27600mAh](https://a.co/d/aW8lNc2)
- For India, some alternative power bank sources are:
  - [Anker Prime Power Bank](https://www.amazon.in/Anker-Portable-Compatible-Charging-Included/dp/B0BYP2F3SG/)
  - [UGREEN 300W 48,000mAh Portable Charger](https://www.amazon.in/UGREEN-Portable-Charger-Digital-Lighting/dp/B0CJY37RT3/)

## 💻 Electronics

| Part | Amount | Unit Cost (US) | Buy (US) | Unit Cost (EU) | Buy (EU) | Unit Cost (CN) | Buy (CN) | Unit Cost (IN) | Buy (IN) |
| --- | --- | --- | --- | --- | --- | --- | --- | --- | --- |
| Raspberry Pi 5 (Optional) | 1 | $60.00 | [Adafruit](https://www.adafruit.com/product/5812) | €57.00 | [Mouser](https://eu.mouser.com/ProductDetail/Raspberry-Pi/SC1111?qs=HoCaDK9Nz5fnLhlMNnKTiQ%3D%3D) | ￥410 | [Taobao](https://e.tb.cn/h.64IIvlisvAL15g8?tk=fdOVexkHECW) | ₹7,999 | [Robu.in](https://robu.in/product/raspberry-pi-5-model-4gb/) |
| Motor Control Board | 2 | $10.55 | [Amazon](https://www.amazon.com/Waveshare-Integrates-Control-Circuit-Supports/dp/B0CTMM4LWK/) | €12.00 | [Amazon](https://www.amazon.fr/Waveshare-Integrates-Control-Applicable-Integrate/dp/B0CJ6TP3TP) | ￥24 | [Taobao](https://e.tb.cn/h.64DOUpLpB5crVdH?tk=BSaTex9UHWj) | ₹4041 | [Amazon India](https://www.amazon.in/Wonrabai-Integrates-Control-Circuit-Supports/dp/B0D1R4SGFS/) |
| microSD card | 1 | $11.23 | [Amazon](https://www.amazon.com/SanDisk-Extreme-microSDXC-Memory-Adapter/dp/B09X7C7LL1/) | €10.00 | [Amazon](https://www.amazon.fr/Lexar-Carte-Micro-adaptateur-Smartphone/dp/B08XZ2KS1F) | ￥58 | [Taobao](https://e.tb.cn/h.64DMZzLz5h26s12?tk=eImPex96lCQ) | ₹739 | [Amazon India](https://www.amazon.in/SanDisk-Extreme-microSD-Smartphones-Action/dp/B0B2DDJGF8/) |
| USB-C to USB-A Cable 2 pcs | 1 | $8.99 | [Amazon](https://a.co/d/0mWsmhG) | €7 | [Amazon](https://www.amazon.fr/dp/B07BNF842T/) | ￥17 | [Taobao](https://e.tb.cn/h.64HOv24RLmYC4Yh?tk=AXpgexkDFd4) | ₹799 | [Amazon India](https://www.amazon.in/Powerline-Charging-Compatibility-Delivery-MacBook/dp/B07DD5YHMH) |
| USB-C Cable 2 pcs | 1 | $8.99 | [Amazon](https://a.co/d/f8hm4E2) | ~€7 | [TODO](https://www.notion.so/Bill-of-Material-21abb280f59380f48e49e5c51df2b37f?pvs=21) | ￥17 | [Taobao](https://detail.tmall.com/item.htm?id=562374737204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) | ₹899 | [Amazon India](https://www.amazon.in/Anker-Charging-MacBook-Galaxy-Charger/dp/B088NRLMPV/) |
| Anker USB Hub | 1 | $15.99 | [Amazon](https://a.co/d/6tJW8lN) |  |  | ￥52 | [Taobao](https://e.tb.cn/h.hTEgXX1RlPY0lWL?tk=AKLz4a3uOsA) | ₹699 | [Amazon India](https://www.amazon.in/Anker-4-Port-Ultra-Extended-MacBook/dp/B07L32B9C2/) |
| 4ft 5264 wires | 1 | $21.99 | [Amazon](https://www.amazon.com/dp/B0D2W47V8V) | ~€20 | [TODO](https://www.notion.so/Bill-of-Material-21abb280f59380f48e49e5c51df2b37f?pvs=21) | ¥20 | [Taobao](https://e.tb.cn/h.6ZvsvUU7wlxTIqu?tk=mz7PeJUloea) 3P-1000mm and 5264 connector | ₹7209 | [Amazon India](https://www.amazon.in/Keszoox-Connector-Assortment-Compatible-Pre-Crimped/dp/B0DCYYWZT7) |
| Type C to DC wire(12V) | 2 | $8.99 | [Amazon 12V](https://www.amazon.com/dp/B0CDBWHXDZ) | ~€8 | [TODO](https://www.notion.so/Bill-of-Material-21abb280f59380f48e49e5c51df2b37f?pvs=21) | ¥20 | [Taobao 12V](https://e.tb.cn/h.6ZvuOW01EmvvHq1?tk=nzvFeJUnyuB) | ₹659 | [Amazon India](https://www.amazon.in/Tobo-7-4x0-6MM-Flexible-Charging-TD-1125CC/dp/B0CQNWRZQ) |



- Raspberry Pi 5 is optional, you can just connect XLeRobot to your laptop for an easier setup.
- Ready-made long 5264 wires are not available for purchase in the US—only **connector kits** are available that require manual assembly to extend the length (still easy).
- In India, one may buy the connectors individually from [Sharvi Electronics](https://sharvielectronics.com/?s=5264&post_type=product&product_cat=0) and assemble them.
- 2 USB-C to USB-A cables to connect the Motor Control Board to Raspberry Pi/PC, USB-C to USB-C cables are also OK as long as your computer supports.
- USB-C cable to connect Raspberry Pi to the battery
- Two Type-C to DC cables (12V) connect the motor control board to the power supply.

## 📷 Sensors 

| Part | Amount | Unit Cost (US) | Buy (US) | Unit Cost (EU) | Buy (EU) | Unit Cost (CN) | Buy (CN) | Unit Cost (IN) | Buy (IN) |
| --- | --- | --- | --- | --- | --- | --- | --- | --- | --- |
| Hand camera | 2 | $12.98 | [Amazon](https://a.co/d/fXX2odP) | ~€10 | [TODO](https://www.notion.so/Bill-of-Material-21abb280f59380f48e49e5c51df2b37f?pvs=21) | ￥99 | [Taobao](https://item.taobao.com/item.htm?ft=t&id=860171734711) | ₹3278 | [Desert Cart](https://www.desertcart.in/products/612412428-innomaker-1080p-usb-2-0-uvc-camera-130-wide-angle) |
| Logitech C920 | 1 | $66 | [Amazon](https://a.co/d/gM8vei1) |  |  | ￥309 |[Taobao]( https://e.tb.cn/h.hjpjA9cw3DpgwQi?tk=DRu642dmCo8 )  | ₹8459 | [Amazon India](https://www.amazon.in/Logitech-C920-Pro-Webcam-Microphones/dp/B006JH8T3S/) |
| RealSense D415 (Optional for Pro) | 1 | $272 | [Intel](https://store.intelrealsense.com/buy-intel-realsense-depth-camera-d415.html) |  |  | ￥1950 |[Taobao](https://e.tb.cn/h.hTHju7zCMDMR84q?tk=z0WU4aXOKey)  | ₹35726 | [Robu.in](https://robu.in/product/intel-d415-realsense-depth-camera/) |



## 🧑‍🤝‍🧑 Alternative choices 

- **IKEA Cart**: You can use a similar cart not from IKEA; however, this may require minor adjustments to the base connector in [3D printed parts](https://github.com/Vector-Wangel/XLeRobot/tree/main/hardware).
- **Batteries**: You can use **other batteries**, but ensure the maximum output capacity can adequately power 2 arms and 3 wheels(~120W=60W*2 ports) (and a RaspberryPi (40W) if you have one).
- **Electronics**: You can use any brand of cables (USB-C cable must be fast-charging type), microSD card, and Raspberry Pi 5 as long as they are compatible.

## 🧩 Optional Add-ons 

- 🫱Soft Gripper Design: The .3mf file contains soft finray fingers that need to be printed with TPU95A. If you want original SO101 finger, just download the original [SO101.stl](https://github.com/Vector-Wangel/XLeRobot/blob/main/hardware/Ender_Follower_SO101.stl) file.
- d2e57534a9e55a3d4dc0d644242cd044
- ✊Better grip stability: [3M gripper tape](https://www.amazon.com/gp/product/B0093CQPW8/ref=ppx_yo_dt_b_search_asin_title?ie=UTF8&psc=1) (got it from [UMI gripper specifications](https://docs.google.com/document/d/1TPYwV9sNVPAi0ZlAupDMkXZ4CA1hsZx7YDMSmcEy6EU/edit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)) Or any other cheaper one (such as tennis grip tape).
- 🙌Dual-arm leader-follower joint control: Additional two [SO100 arm sets](https://github.com/TheRobotStudio/SO-ARM100/tree/main) for dual-arm leader-follower joint control
- 👗Sleeves: To hide the cables and give XLeRobot a better outfit, just buy the cheapest sport sleeves you can find. [I bought one randomly on Amazon.](https://a.co/d/bjD08Oi)
- 👀VR control: Meta Quest 3 (or 3S)
- For more add-ons and accessories, check out the [SO101 arm repository](https://github.com/TheRobotStudio/SO-ARM100/tree/main?tab=readme-ov-file#optional-hardware)

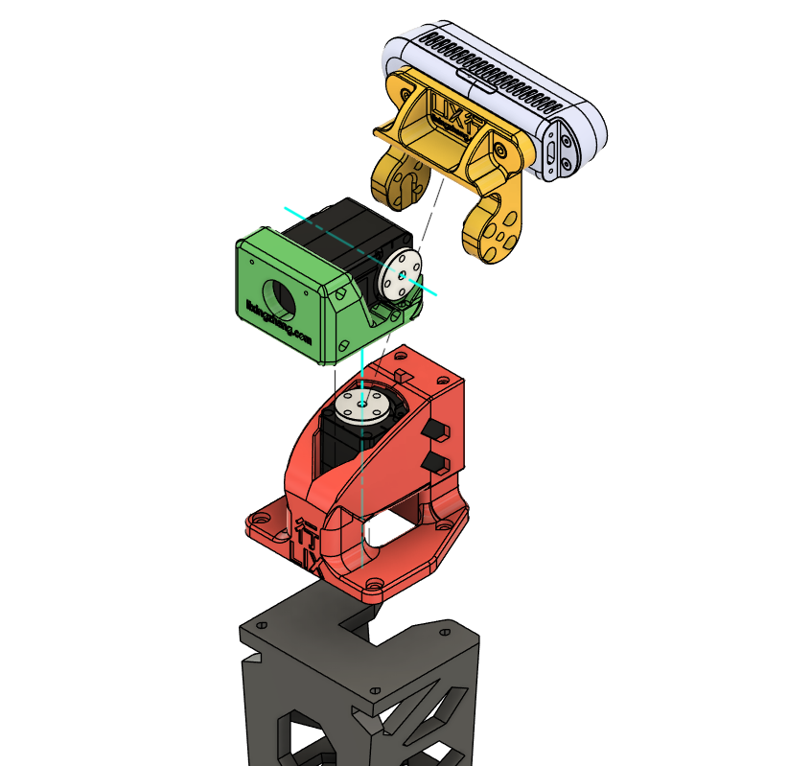
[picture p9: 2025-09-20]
hardware/step/RGBD_Gimbal/Explosion_Nimbal_Parts.png

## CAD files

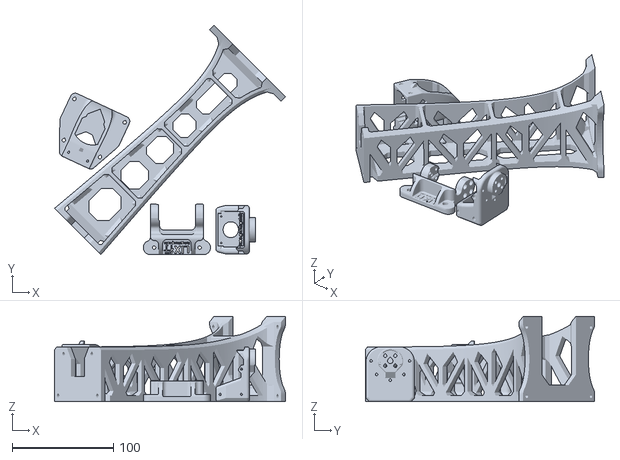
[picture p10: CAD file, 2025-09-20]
hardware/Gimbal_mesh_all_d435.stl
228.0 x 226.5 x 84.0

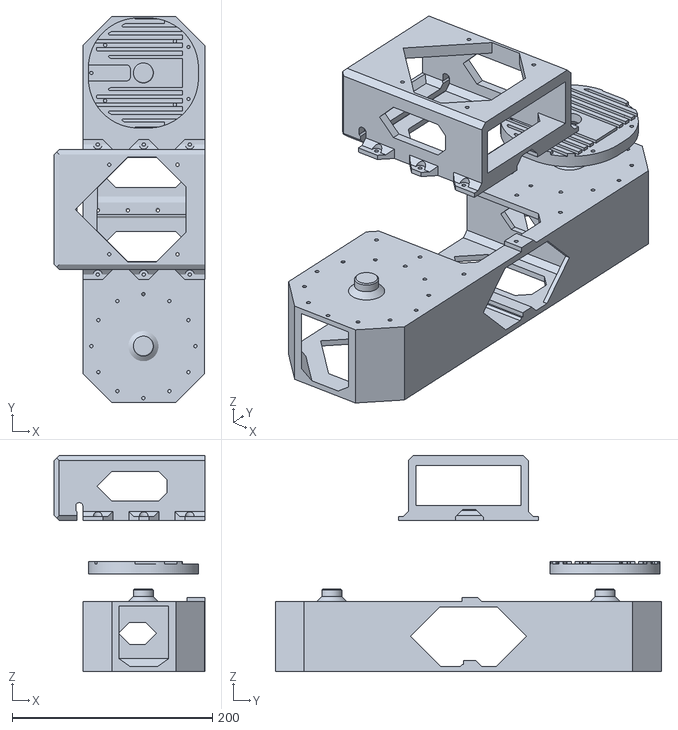
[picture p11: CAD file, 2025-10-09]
hardware/ongoing_upgrades/XLeRobot 035 armbase.stl
150.5 x 386.3 x 216.0

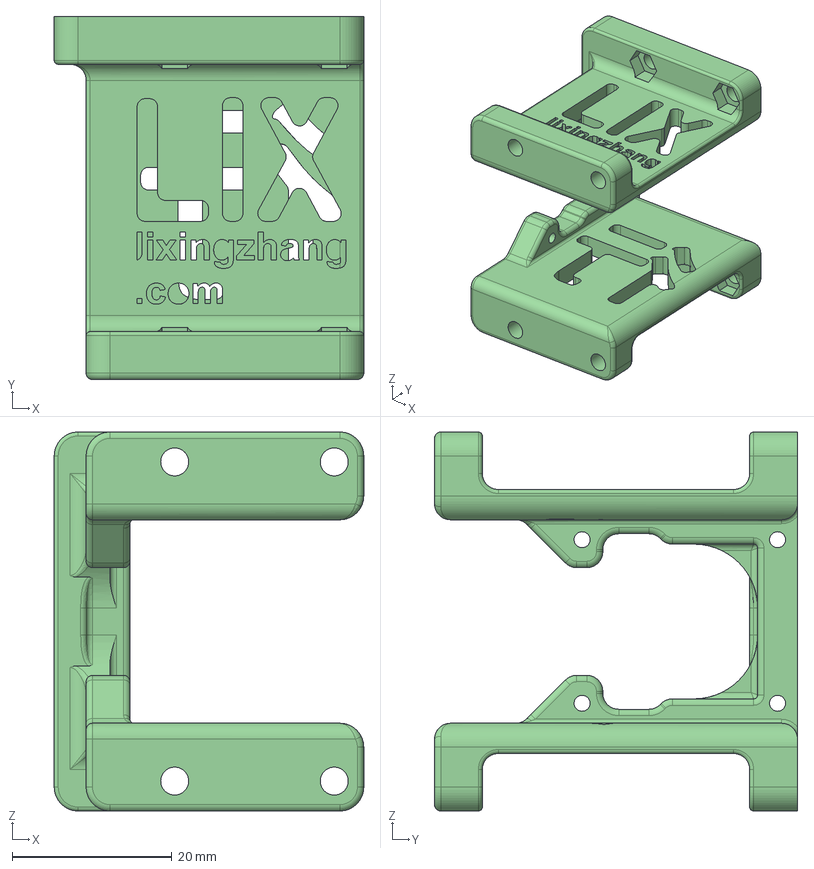
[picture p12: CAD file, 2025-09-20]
hardware/step/Drive_Motor_Mount_upgraded.step
38.8 x 45.5 x 47.5 mm

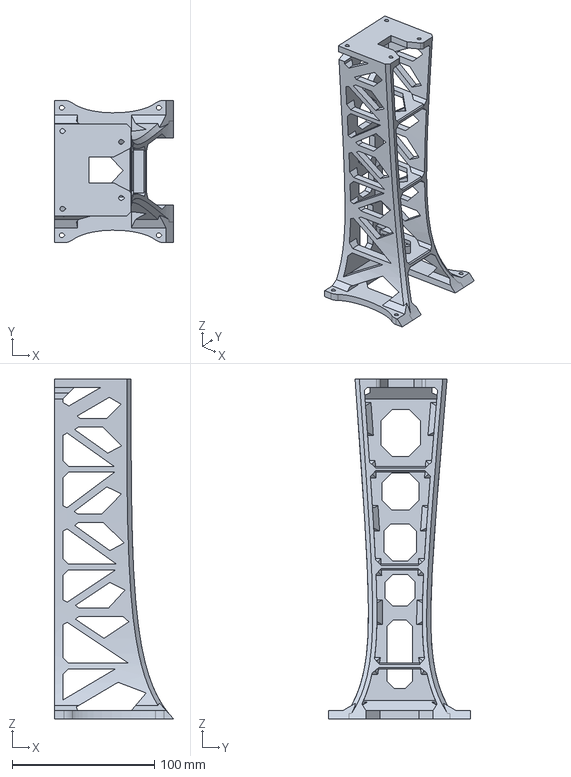
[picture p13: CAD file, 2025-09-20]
hardware/step/RGBD_Gimbal/Gimbal_Neck.step
84.0 x 100.0 x 239.0 mm

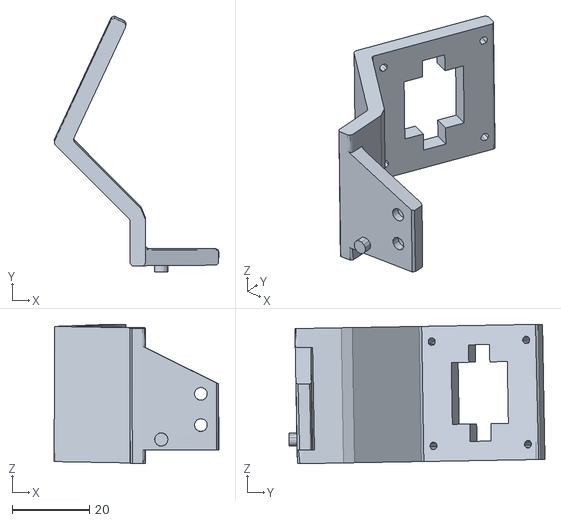
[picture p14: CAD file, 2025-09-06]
simulation/Maniskill/assets/xlerobot/meshes/XLeRobot_camera1.stl
42.6 x 66.3 x 36.1

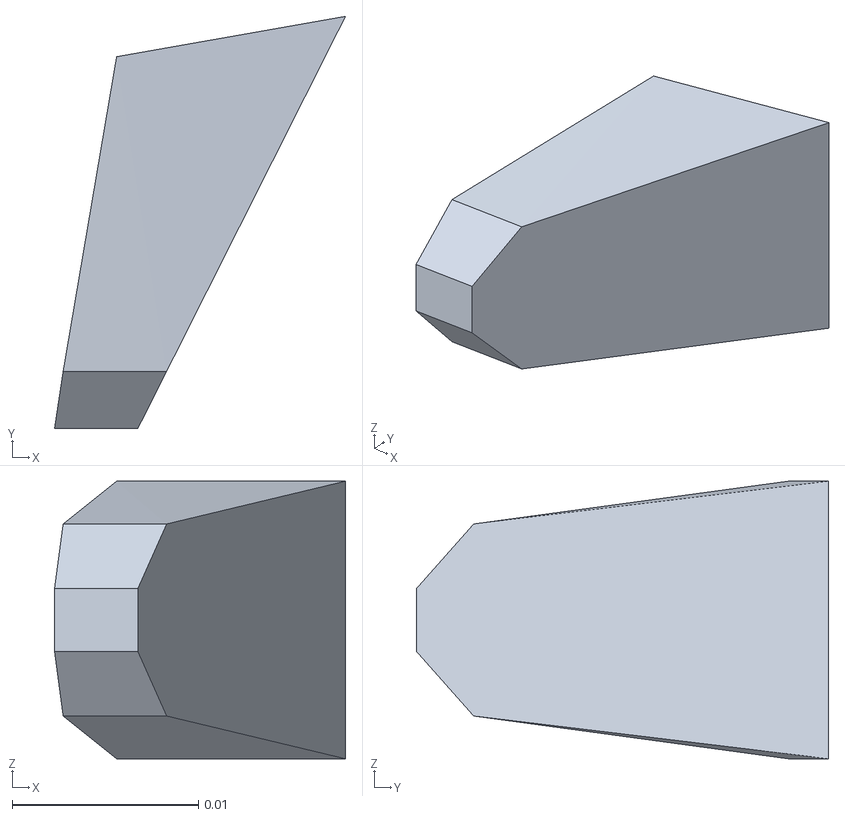
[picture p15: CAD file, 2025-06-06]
simulation/mujoco/assets/Moving_Jaw_Collision_1.stl
0.0156 x 0.0221 x 0.0149

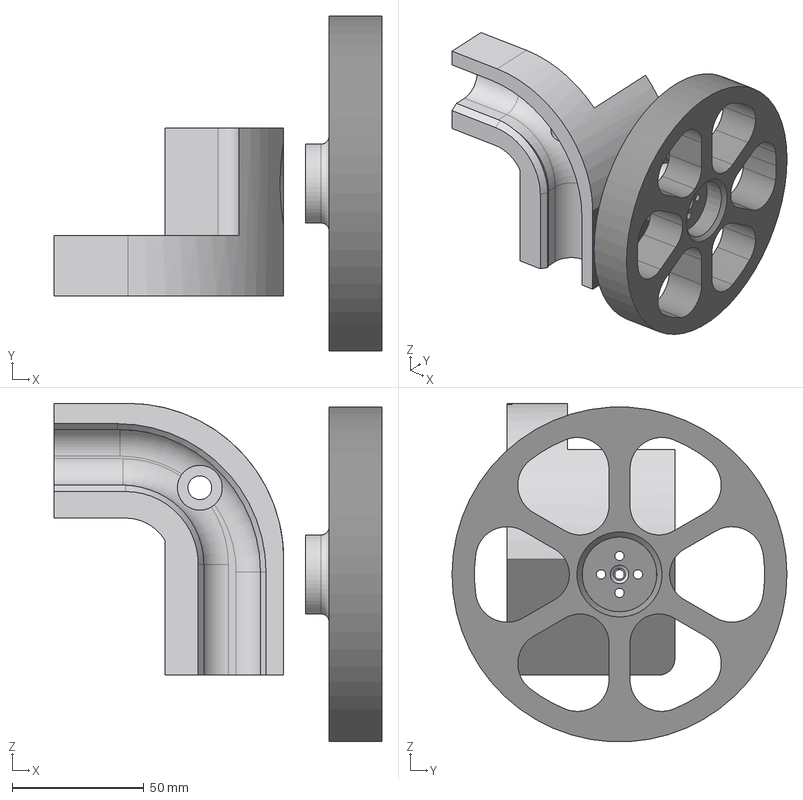
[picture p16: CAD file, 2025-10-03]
hardware/ongoing_upgrades/XLeRobot 035 wheels.step
124.2 x 127.0 x 128.3 mm
Circular Pattern 01
omni_wheel_mount v5:3

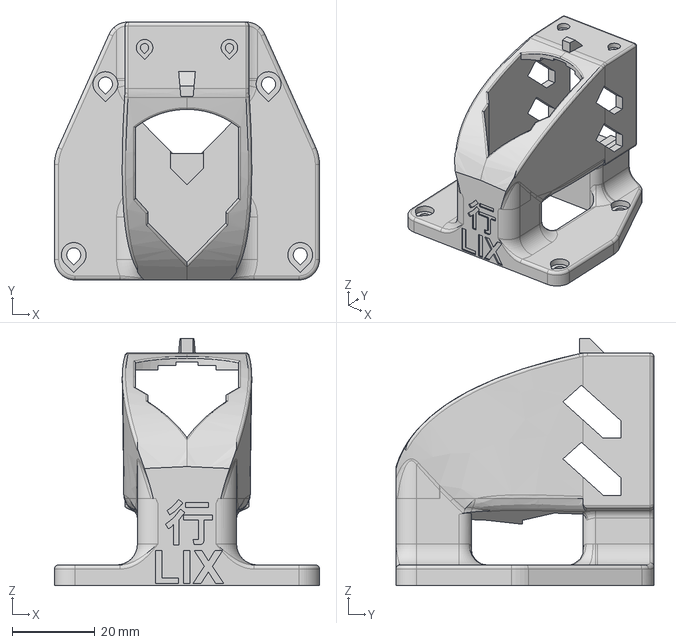
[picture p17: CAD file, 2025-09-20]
hardware/step/RGBD_Gimbal/Gimbal_Base.step
64.0 x 62.3 x 59.7 mm

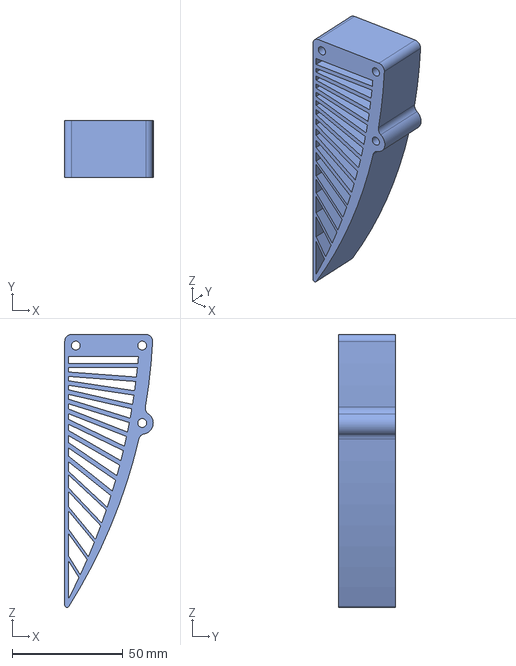
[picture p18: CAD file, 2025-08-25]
hardware/step/soft_gripper_finger.step
40.0 x 25.8 x 123.4 mm

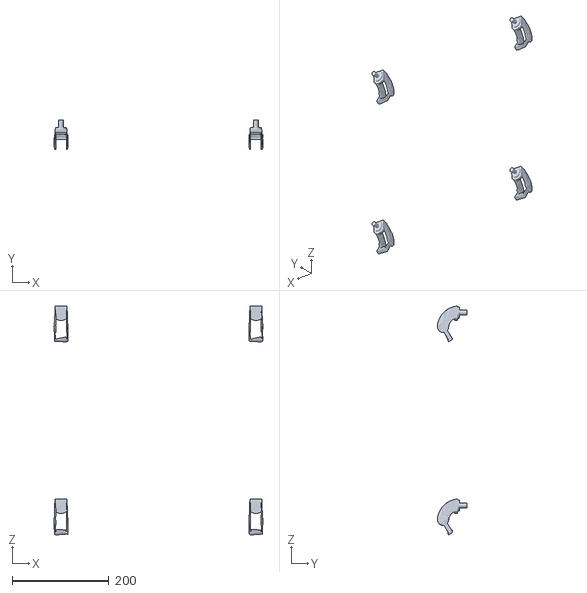
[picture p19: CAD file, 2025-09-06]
simulation/Maniskill/assets/xlerobot/meshes/raskogwheel1.stl
432.7 x 61.2 x 474.6

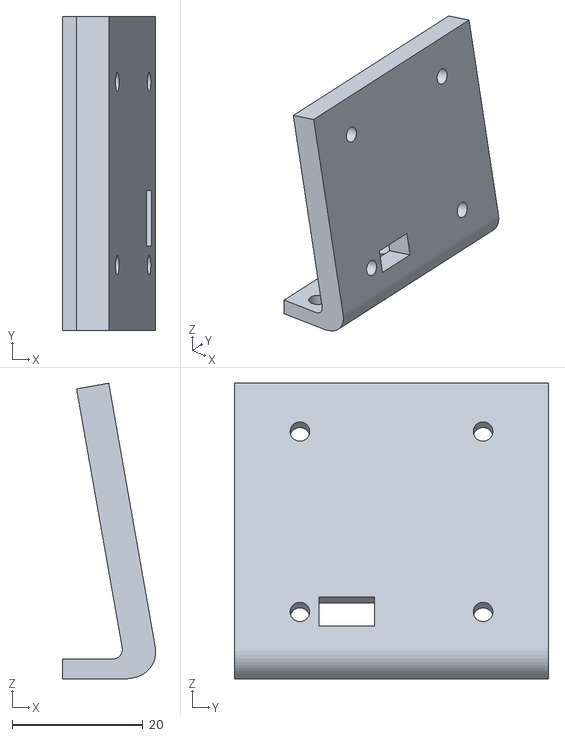
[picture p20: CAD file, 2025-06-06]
simulation/mujoco/assets/Camera-Mount-v6.stl
14.3 x 48.0 x 45.2

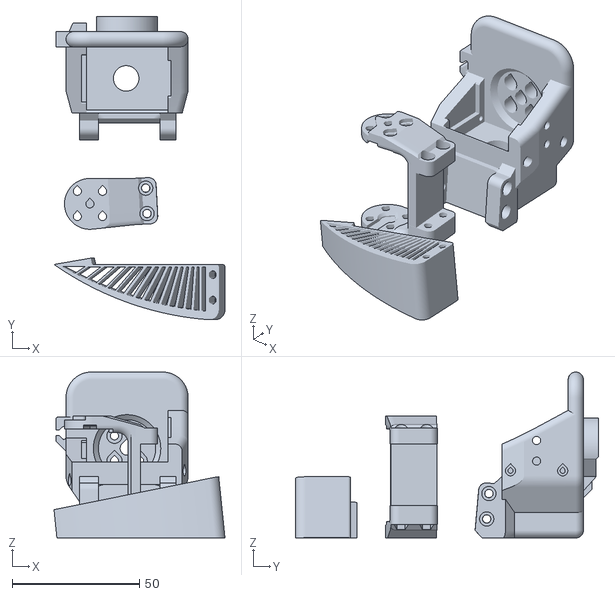
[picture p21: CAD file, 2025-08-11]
hardware/SO101_soft_fin.stl
67.2 x 119.2 x 65.2

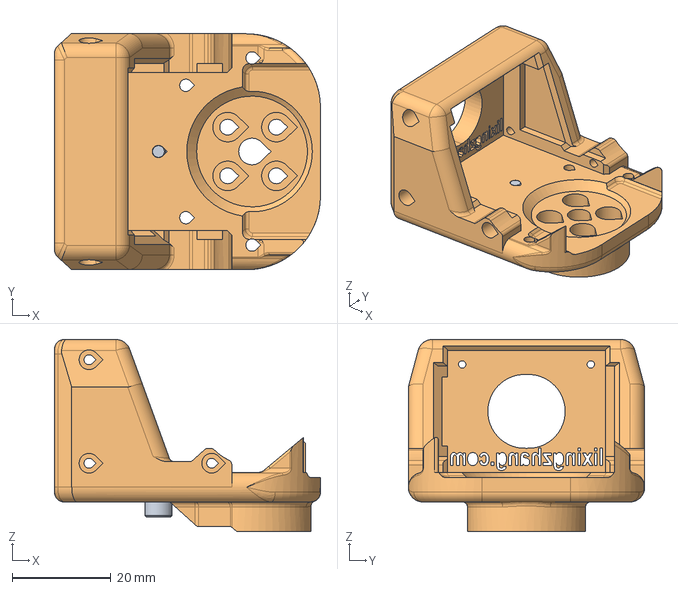
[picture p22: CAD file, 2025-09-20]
hardware/step/RGBD_Gimbal/Gimbal_Yaw.step
54.0 x 48.0 x 39.0 mm

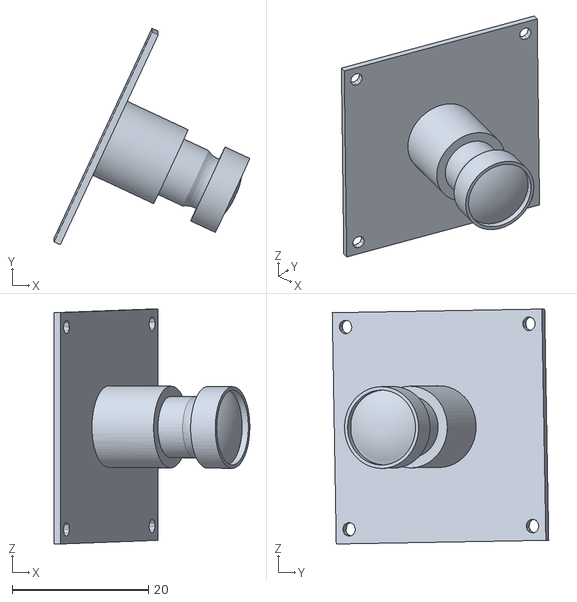
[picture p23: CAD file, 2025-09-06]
simulation/Maniskill/assets/xlerobot/meshes/XLeRobot_camera2.stl
28.8 x 31.8 x 34.5

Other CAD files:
hardware/Gimbal_mesh_all_d455.stl
simulation/mujoco/assets/STS3215_03a-v1.stl
hardware/step/RGBD_Gimbal/Gimbal_Pitch_Holder_d435.step
simulation/Maniskill/assets/xlerobot/meshes/tophead5.stl
hardware/ongoing_upgrades/XLeRobot 035 wheels.stl
hardware/step/Archiv/Headmount.step
hardware/step/Archiv/Neck.step
hardware/step/RGBD_Gimbal/Gimbal_Pitch_Holder_d455.step
simulation/Maniskill/assets/xlerobot/meshes/Base.stl
simulation/Maniskill/assets/xlerobot/meshes/Base.stl.convex.stl
simulation/Maniskill/assets/xlerobot/meshes/Base_Motor.stl
simulation/Maniskill/assets/xlerobot/meshes/Base_Motor.stl.convex.stl
simulation/Maniskill/assets/xlerobot/meshes/Fixed_Jaw.stl
simulation/Maniskill/assets/xlerobot/meshes/Fixed_Jaw.stl.convex.stl
simulation/Maniskill/assets/xlerobot/meshes/Fixed_Jaw_Motor.stl
simulation/Maniskill/assets/xlerobot/meshes/Fixed_Jaw_Motor.stl.convex.stl
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

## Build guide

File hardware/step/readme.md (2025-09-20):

## Editable Step File

Here stores all the editable step files for developers to design their own parts compatible with XLeRobot.

Update Sep.20.2025 by Lix: New gimbal design and upgraded driver motor mount can now be found in the repository.

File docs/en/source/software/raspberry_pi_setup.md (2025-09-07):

# RaspberryPi Setup Guide for XLeRobot

This guide provides comprehensive instructions for setting up a RaspberryPi for use with XLeRobot mobile base version.

## Prerequisites

- RaspberryPi (recommended: Pi 4 or newer)
- MicroSD card (32GB or larger recommended)
- Computer with SD card reader
- Network connection (WiFi or Ethernet)

## 1. Installing the Operating System

### Download Raspberry Pi OS
1. Visit the [official Raspberry Pi website](https://www.raspberrypi.org/software/)
2. Download Raspberry Pi Imager
3. Download Raspberry Pi OS (recommended: Raspberry Pi OS with desktop)

### Flash the OS to SD Card
1. Insert your microSD card into your computer
2. Open Raspberry Pi Imager
3. Select the downloaded OS image
4. Select your SD card
5. Click "Write" to flash the OS

### Initial Setup
1. Insert the SD card into your RaspberryPi
2. Connect keyboard, mouse, and monitor
3. Power on the RaspberryPi
4. Follow the initial setup wizard:
   - Set country, language, and timezone
   - Create user account and password
   - Connect to WiFi network
   - Update system packages

```{note}
The hostname option defines the hostname your Raspberry Pi broadcasts to the network using mDNS. When you connect your Raspberry Pi to your network, other devices on the network can communicate with your computer using `<hostname>`.local or `<hostname>`.lan.

The username and password option defines the username and password of the admin user account on your Raspberry Pi.

The wireless LAN option allows you to enter an SSID (name) and password for your wireless network. If your network does not broadcast an SSID publicly, you should enable the "Hidden SSID" setting. By default, Imager uses the country you’re currently in as the "Wireless LAN country". This setting controls the Wi-Fi broadcast frequencies used by your Raspberry Pi. Enter credentials for the wireless LAN option if you plan to run a headless Raspberry Pi.

```

   Raspberry Pi OS Customisation

## 2. Setting Up VNC for Remote Desktop

### Enable VNC Server
1. Open Terminal on RaspberryPi
2. Run the configuration tool:
```bash
sudo raspi-config
```
3. Navigate to "Interface Options" → "VNC" → "Enable"
4. Reboot the system

### Alternative: Enable VNC via Command Line
```bash
sudo systemctl enable vncserver-x11-serviced
sudo systemctl start vncserver-x11-serviced
```

### Install VNC Viewer on Your PC
1. Download [RealVNC Viewer](https://www.realvnc.com/en/connect/download/viewer/)
2. Install and launch VNC Viewer
3. Connect using `<hostname>`.local or `<hostname>`.lan, for me is XLerobot.local **(Make sure these devices are in the same network)**
4. Use your Pi's username and password to authenticate



For detailed VNC setup instructions, refer to [this comprehensive guide](https://www.raspberrypi.com/documentation/computers/remote-access.html#vnc).

## 3. System Updates and Dependencies

### Update System Packages
```bash
sudo apt update
sudo apt upgrade -y
```

### Install Essential Packages
```bash
sudo apt install -y python3-pip git curl wget
```

## 4. Enable SSH Access (Optional)

### Enable SSH
```bash
sudo systemctl enable ssh
sudo systemctl start ssh
```

### Find Your Pi's IP Address
```bash
hostname -I
```

### Connect from Your PC
```bash
ssh pi@<your-pi-ip-address>
```

## 5. Installing XLeRobot Software

Follow the official [software installation instructions](https://huggingface.co/docs/lerobot/installation#install-lerobot-) for detailed steps.

And copy the [config files](https://xlerobot.readthedocs.io/en/latest/index.html).

## Next Steps

After completing this setup, you can run the code in the same way as the laptop:



## Additional Resources

- [Official Raspberry Pi Documentation](https://www.raspberrypi.org/documentation/)
- [RealVNC Setup Guide](https://pidoc.cn/docs/computers/getting-started)
- [XLeRobot GitHub Repository](https://xlerobot.readthedocs.io/en/latest/index.html)

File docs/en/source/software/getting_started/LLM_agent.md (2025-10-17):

## LLM Agent Control

Imagine telling the robot "go cleanup my kitchen" and watching him doing so. This tutorial will show you how you can make your XLeRobot fully autonomous, self-decision making machine by providing it with LLM agent. An agent that, by seeing world through camera and hearing your voice commands, be able to move the robot and (in the future) manipulate objects using VLA policies.

## Getting Started

To create our agent, we will use the [RoboCrew](https://github.com/Grigorij-Dudnik/RoboCrew) library - one specially designed for embodied agents. On your control device (Raspberry Pi or laptop) create a new virtual envinronment and install it with:

```bash
pip install robocrew
```

Next, create the python script to control your robot. Let's start by creating a simple agent that performs just one hardcoded task and finishes. 

First, let's create tools for agent to control a wheel movement:

```python
from robocrew.core.LLMAgent import LLMAgent
from robocrew.core.tools import finish_task
from robocrew.robots.XLeRobot.tools import create_move_forward, create_turn_left, create_turn_right
from robocrew.robots.XLeRobot.wheel_controls import XLeRobotWheels

# Set up wheels
sdk = XLeRobotWheels.connect_serial("/dev/ttyUSB0")     # provide the right arm usb port - the arm connected to wheels
wheel_controller = XLeRobotWheels(sdk)

# Create movement tools
move_forward = create_move_forward(wheel_controller)
turn_left = create_turn_left(wheel_controller)
turn_right = create_turn_right(wheel_controller)
```

in place of `"/dev/ttyUSB0"` you should provide the USB port name of your right arm (one connected to wheels).

ToDo: add here a short instruction on how to find USB port names and how to bind them to specific devices to avoid usb name swapping.

Next, let's initialize agent itself:

```python
# Create agent
agent = LLMAgent(
    model="google_genai:gemini-robotics-er-1.5-preview",
    tools=[move_forward, turn_left, turn_right, finish_task],
    main_camera_usb_port="/dev/video0",     # provide usb port main camera connected to
    camera_fov=110,
)
agent.task = "Find kitchen in my house and go there."

agent.go()
```

In place of `"/dev/video0"` you need to provide USB port name of your main camera.

In the code above we initialized our agent with the maneuver tools we created earlier. You can provide any model in LangChain notation. Next, we hard-coding a task for our agent and running it.

Before going to LLM, camera image is specially augmented to make it easier for robot predict his angle of rotation. Special scale of angles is added to the camera, plus right/left markers - LLM likes to mismatch directions. That's why we specifing `camera_fov` parameter - provide here your main camera horizontal angle of view, to make drawn scale precise.

<div style="text-align: center; font-style: italic">
  
  <p>That's how your robot sees the world.</p>
</div>

Also, create the `.env` file with parameter `GOOGLE_API_KEY=<your gemini api key here>` inside to connect to your model.

Now run the code and watch if your XLeRobot will be able to find that kitchen - then it will finish its work by calling `finish_task` tool!

Complete code is here:

```python
from robocrew.core.LLMAgent import LLMAgent
from robocrew.core.tools import finish_task
from robocrew.robots.XLeRobot.tools import create_move_forward, create_turn_left, create_turn_right
from robocrew.robots.XLeRobot.wheel_controls import XLeRobotWheels

# Set up wheels
sdk = XLeRobotWheels.connect_serial("/dev/ttyUSB0")     # provide the right arm usb port - the arm connected to wheels
wheel_controller = XLeRobotWheels(sdk)

# Create movement tools
move_forward = create_move_forward(wheel_controller)
turn_left = create_turn_left(wheel_controller)
turn_right = create_turn_right(wheel_controller)

# Create agent
agent = LLMAgent(
    model="google_genai:gemini-robotics-er-1.5-preview",
    tools=[move_forward, turn_left, turn_right, finish_task],
    main_camera_usb_port="/dev/video0",     # provide usb port main camera connected to
    camera_fov=110,
)
agent.task = "Find kitchen in my house and go there."

agent.go() 
```

## Voice-conrolled agent

Now that we have managed to run our simple agent, let's add him an ability to listen to our voice commands through the microphone.

First, we need to install Portaudio, to enable our control device to hear:

```bash
sudo apt install portaudio19-dev
```

Tools initialization remains the same as in previous example - the only change here is we no longer need the `finish_task` tool anymore, as our agent will be listen for our tasks and operate in endless (untill we shut down the script).

What changes is the agent initialization:

```python
agent = LLMAgent(
    model="google_genai:gemini-robotics-er-1.5-preview",
    tools=[move_forward, turn_left, turn_right],
    main_camera_usb_port="/dev/video0",  # provide usb port main camera connected to
    sounddevice_index=0,  # Your mic device
    wakeword="robot",  # The robot listens for this word in your speech
    history_len=4,
)

agent.go()
```

As you can see, we need to provide index of our soundcard with microphone. We can also set up our wakeword (default is "robot") - when robot hears that word in your sentence, it threats it as its new task; otherwise ignores it.

ToDo: short instruction on how to find soundcard index and make it constant.

We can also set up `history_len` - how many of last movements robot should keep in the memory, to avoid memory overflow.

Run the code and ask the robot to do something for you!

Complete code is here:

```python
from robocrew.core.LLMAgent import LLMAgent
from robocrew.robots.XLeRobot.tools import create_move_forward, create_turn_left, create_turn_right
from robocrew.robots.XLeRobot.wheel_controls import XLeRobotWheels

# Set up wheels
sdk = XLeRobotWheels.connect_serial("/dev/ttyUSB0")     # provide the right arm usb port - the arm connected to wheels
wheel_controller = XLeRobotWheels(sdk)

# Create movement tools
move_forward = create_move_forward(wheel_controller)
turn_left = create_turn_left(wheel_controller)
turn_right = create_turn_right(wheel_controller)

# Create agent
agent = LLMAgent(
    model="google_genai:gemini-robotics-er-1.5-preview",
    tools=[move_forward, turn_left, turn_right],
    main_camera_usb_port="/dev/video0",  # provide usb port main camera connected to
    sounddevice_index=0,  # Your mic device
    wakeword="robot",  # The robot listens for this word in your speech
    history_len=4,
)

agent.go() 
```

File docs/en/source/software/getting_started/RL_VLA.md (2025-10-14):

## Reinforcenment Learning (RL)

You can try [lerobot-sim2real (by Stone Tao)](https://github.com/StoneT2000/lerobot-sim2real) with Maniskill, or [huggingface official tutorial on HIL-SERL](https://huggingface.co/docs/lerobot/hilserl) on single SO101 arm first. The offcial code for complete XLeRobot RL is coming soon. The demo below shows the implementation of [lerobot-sim2real](https://github.com/StoneT2000/lerobot-sim2real), with minor changes to the camera direction and sim-object distribution. 

<video width="100%" controls>
  <source src="https://vector-wangel.github.io/XLeRobot-assets/videos/Real_demos/sim2real_2.mp4" type="video/mp4">
  Your browser does not support the video tag.
</video>

## VLA

You can follow [huggingface official VLA tutorial](https://huggingface.co/docs/lerobot/smolvla) on single SO101 arm first.  The offcial code for the complete XLeRobot VLA is coming soon.

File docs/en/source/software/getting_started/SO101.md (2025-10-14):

## SO100/SO101 Arm Examples

### Keyboard Joint Control

The most basic control method using direct joint angle manipulation. Run `0_so100_keyboard_joint_control.py` for manual control of individual joint positions using keyboard inputs. This provides direct access to each joint's movement without inverse kinematics calculations.

### Keyboard End-Effector Control

Advanced control using inverse kinematics to move the end-effector in Cartesian space. Run `1_so100_keyboard_ee_control.py` for intuitive control where keyboard inputs control the end-effector position (X, Y coordinates) rather than individual joints.

<video width="100%" controls>
  <source src="https://vector-wangel.github.io/XLeRobot-assets/videos/Real_demos/keyboard_teleop.mp4" type="video/mp4">
  Your browser does not support the video tag.
</video>

### Dual-Arm Keyboard Control

Simultaneous control of two SO100 arms connected via different serial ports (/dev/ttyACM0 and /dev/ttyACM1). Run `2_dual_so100_keyboard_ee_control.py` for coordinated dual-arm manipulation with separate keyboard mappings for each arm.

### Vision-based Object Following

YOLO-powered object detection and tracking system. Run `3_so100_yolo_ee_control.py` to enable the robot to automatically follow detected objects (such as bottles) using computer vision. This demo requires no training and combines real-time object detection with end-effector control. 

You can check [Ultralytics official website](https://docs.ultralytics.com/models/) to try all kinds of different Vision-related models and applications in an extremely easy way.

<video width="100%" controls>
  <source src="https://vector-wangel.github.io/XLeRobot-assets/videos/Real_demos/yolo.mp4" type="video/mp4">
  Your browser does not support the video tag.
</video>

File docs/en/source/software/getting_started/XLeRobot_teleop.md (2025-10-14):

### XLeRobot Teleop

### FAQ

- If you are using Ubuntu, be sure to run `sudo chmod 666 /dev/ttyACM0` and `sudo chmod 666 /dev/ttyACM1` after plugging in the motor control board.
- Then run `python lerobot/find_port.py` to check the control board ID. Then change the names correspondingly in
- 
- If you are having error of not detecting any motor after `sudo chmod ...`, try replugging the power cable.
- If you are having error of `need 9 motors, but 8 detected`, you need to switch the port names in the above figure.

### Keyboard Teleop

Complete system control including dual arms, mobile base, and head motors. Run [4_xlerobot_teleop_keyboard.py](https://github.com/Vector-Wangel/XLeRobot/blob/main/software/examples/4_xlerobot_teleop_keyboard.py) for comprehensive keyboard-based teleoperation of the entire XLeRobot system with separate key mappings for left arm, right arm, base movement, and head control.

### Xbox Controller Teleop

Intuitive gamepad control for the full XLeRobot system. Run [5_xlerobot_teleop_xbox.py](https://github.com/Vector-Wangel/XLeRobot/blob/main/software/examples/5_xlerobot_teleop_xbox.py) for Xbox controller-based teleoperation with ergonomic stick and trigger mappings for natural human-robot interaction.

<video width="100%" controls>
  <source src="https://vector-wangel.github.io/XLeRobot-assets/videos/Real_demos/xlerobot_025_001.mp4" type="video/mp4">
  Your browser does not support the video tag.
</video>

### Switch Joycon Teleop

- The Joycon teleop is built based the repo [joycon-robotics (by box2ai)](https://github.com/box2ai-robotics/joycon-robotics). So first you need to git clone that repo and install it following its guide (including installing external packages and make install). Then directly replace all the codes with [my modified version](https://github.com/Vector-Wangel/XLeRobot/tree/main/software/joyconrobotics).

- Based on my own experience, it's recommended to also run `sudo apt install joycond` and `sudo systemctl enable --now joycond` to ensure better bluetooth connection. 

- Put your Joy-Con(s) in pairing mode: Hold down the small sync button on the side of the Joy-Con (between SR and SL buttons) until the lights (single dot) start flashing
- Open Bluetooth settings: Go to Settings → Bluetooth (or use bluetoothctl from terminal).
  - Look for "Joy-Con (L)" or "Joy-Con (R)" in the device list
  - Click to pair each one, then you should see the lights (multiple dots) flashing
  - Then press: Left: L (upper trigger) + Right: R (upper trigger) together, and you should see only the first light dot on both joycons is on, meaning the connection is successful.
- You can run the test file `joycon_test_read.py` first to ensure successful connection.
- Then you can run `6_so100_joycon_ee_control.py` for single SO101 arm control (only one joycon needed) as shown below, and `7_xlerobot_teleop_joycon.py` for the complete XLeRobot teleop (this is what I used for most of the teleoping home tasks in the 0.3.0 demo).

### VR Teleop

You can try [controlling XLeRobot with VR in simulation](https://xlerobot.readthedocs.io/en/latest/simulation/getting_started/vr_sim.html) first. The offical code for VR teleop the real robot is coming soon.

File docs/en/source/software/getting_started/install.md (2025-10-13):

### Install LeRobot 🤗

To install LeRobot, follow the [official Installation Guide](https://huggingface.co/docs/lerobot/installation)

```{note}
It's recommended to use `pip install -e .` for a more convenient file transfer.
```

Configure the motors for [SO101 arms](https://huggingface.co/docs/lerobot/so101#configure-the-motors) and [other motors](https://xlerobot.readthedocs.io/en/latest/hardware/getting_started/assemble.html#configure-motors) if you haven't done so.

## Move XLeRobot files 

Open the installed lerobot folder and:

Move my analytical IK solver for SO101 robot to the /model folder


Move xlerobot robot folder the /robots folder.


```{note}
If you want to build based on RaspberryPi, uncomment xlerobot_host and xlerobot_client in __init__.py.
```
Move all the example codes to /example folder.


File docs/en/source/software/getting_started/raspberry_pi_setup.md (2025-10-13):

# RaspberryPi Setup Guide for XLeRobot

This guide provides comprehensive instructions for setting up a RaspberryPi for use with XLeRobot mobile base version.

## Prerequisites

- RaspberryPi (recommended: Pi 4 or newer)
- MicroSD card (32GB or larger recommended)
- Computer with SD card reader
- Network connection (WiFi or Ethernet)

## 1. Installing the Operating System

### Download Raspberry Pi OS
1. Visit the [official Raspberry Pi website](https://www.raspberrypi.org/software/)
2. Download Raspberry Pi Imager
3. Download Raspberry Pi OS (recommended: Raspberry Pi OS with desktop)

### Flash the OS to SD Card
1. Insert your microSD card into your computer
2. Open Raspberry Pi Imager
3. Select the downloaded OS image
4. Select your SD card
5. Click "Write" to flash the OS

### Initial Setup
1. Insert the SD card into your RaspberryPi
2. Connect keyboard, mouse, and monitor
3. Power on the RaspberryPi
4. Follow the initial setup wizard:
   - Set country, language, and timezone
   - Create user account and password
   - Connect to WiFi network
   - Update system packages

```{note}
The hostname option defines the hostname your Raspberry Pi broadcasts to the network using mDNS. When you connect your Raspberry Pi to your network, other devices on the network can communicate with your computer using `<hostname>`.local or `<hostname>`.lan.

The username and password option defines the username and password of the admin user account on your Raspberry Pi.

The wireless LAN option allows you to enter an SSID (name) and password for your wireless network. If your network does not broadcast an SSID publicly, you should enable the "Hidden SSID" setting. By default, Imager uses the country you’re currently in as the "Wireless LAN country". This setting controls the Wi-Fi broadcast frequencies used by your Raspberry Pi. Enter credentials for the wireless LAN option if you plan to run a headless Raspberry Pi.

```

   Raspberry Pi OS Customisation

## 2. Setting Up VNC for Remote Desktop

### Enable VNC Server
1. Open Terminal on RaspberryPi
2. Run the configuration tool:
```bash
sudo raspi-config
```
3. Navigate to "Interface Options" → "VNC" → "Enable"
4. Reboot the system

### Alternative: Enable VNC via Command Line
```bash
sudo systemctl enable vncserver-x11-serviced
sudo systemctl start vncserver-x11-serviced
```

### Install VNC Viewer on Your PC
1. Download [RealVNC Viewer](https://www.realvnc.com/en/connect/download/viewer/)
2. Install and launch VNC Viewer
3. Connect using `<hostname>`.local or `<hostname>`.lan, for me is XLerobot.local **(Make sure these devices are in the same network)**
4. Use your Pi's username and password to authenticate



For detailed VNC setup instructions, refer to [this comprehensive guide](https://www.raspberrypi.com/documentation/computers/remote-access.html#vnc).

## 3. System Updates and Dependencies

### Update System Packages
```bash
sudo apt update
sudo apt upgrade -y
```

### Install Essential Packages
```bash
sudo apt install -y python3-pip git curl wget
```

## 4. Enable SSH Access (Optional)

### Enable SSH
```bash
sudo systemctl enable ssh
sudo systemctl start ssh
```

### Find Your Pi's IP Address
```bash
hostname -I
```

### Connect from Your PC
```bash
ssh pi@<your-pi-ip-address>
```

## 5. Installing XLeRobot Software

Follow the official [software installation instructions](https://huggingface.co/docs/lerobot/installation#install-lerobot-) for detailed steps.

And copy the [config files](https://xlerobot.readthedocs.io/en/latest/index.html).

## Next Steps

After completing this setup, you can run the code in the same way as the laptop:



## Additional Resources

- [Official Raspberry Pi Documentation](https://www.raspberrypi.org/documentation/)
- [RealVNC Setup Guide](https://pidoc.cn/docs/computers/getting-started)
- [XLeRobot GitHub Repository](https://xlerobot.readthedocs.io/en/latest/index.html)

## Lekiwi

```{note}
To test the single-arm version of XLeRobot with Lekiwi codes, you should detach the SO101 arm that doesn't share the same motor control board with the base, clamp it on your table and connect it to your PC to act as the leader arm.
```
```{note}
To run mobile base version of Lekiwi, you need a RaspberryPi in advance.
```

Follow all of their [software instructions](https://huggingface.co/docs/lerobot/lekiwi) so you can:
-  [Setup VNCviewer for RasberryPi](getting_started/raspberry_pi_setup.md)
-  [Install software on RasberryPi](https://huggingface.co/docs/lerobot/lekiwi#install-software-on-pi) and setup SSH 
-  [Install LeRobot on PC](https://huggingface.co/docs/lerobot/installation)
-  [Update config](https://github.com/huggingface/lerobot/blob/main/examples/11_use_lekiwi.md#update-config)
-  [Calibrate](https://huggingface.co/docs/lerobot/il_robots#set-up-and-calibrate)

After these steps you should be able to teleoperate a basic single-arm version of XLeRobot [the same way Lekiwi does](https://github.com/huggingface/lerobot/blob/main/examples/11_use_lekiwi.md#f-teleoperate), to replicate this demo video:

<video width="100%" style="max-width: 100%;" controls>
  <source src="https://github.com/user-attachments/assets/98312e30-9a5d-41a1-a6ce-ef163c3abfd5" type="video/mp4">
  Your browser does not support the video tag.
</video>

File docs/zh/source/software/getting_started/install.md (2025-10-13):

### 安装LeRobot 🤗

要安装LeRobot，请按照[官方安装指南](https://huggingface.co/docs/lerobot/installation)

```{note}
建议使用`pip install -e .`以便更方便的文件传输。
```

如果您还没有配置[SO101手臂](https://huggingface.co/docs/lerobot/so101#configure-the-motors)和[其他电机](https://xlerobot.readthedocs.io/en/latest/hardware/getting_started/assemble.html#configure-motors)的电机，请进行配置。

## 移动XLeRobot文件 

打开已安装的lerobot文件夹并：

将我的SO101机器人解析逆运动学求解器移动到/model文件夹


将xlerobot机器人文件夹移动到/robots文件夹。


```{note}
如果您想基于树莓派构建，请在__init__.py中取消注释xlerobot_host和xlerobot_client。
```
将所有示例代码移动到/example文件夹。


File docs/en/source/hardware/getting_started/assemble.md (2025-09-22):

# ⚒️ Assembly



> Estimated Assembly time: From scratch: 2-4 hrs; with assembled SO100/SO101 arms: 1-2 hrs
> 
```{tip}
You can also buy [pre-assembled kits](https://github.com/TheRobotStudio/SO-ARM100#kits) for SO101 arms.

```
<iframe width="800" height="600" 
    src="https://www.youtube.com/embed/upB1CEFeOlk" 
    frameborder="0" 
    allowfullscreen>
</iframe>

## 🦾 SO101 Arms



> If you already have 2x SO101 arms assembled with motors configured, skip.
>

- Build 2x SO101 arms by following [SO101 Step-by-Step Assembly Instructions](https://huggingface.co/docs/lerobot/so101) to build 2 identical follower arms with 2 sets of motors (both previous indexed as 1-6) for 2 control boards.
- Then continue to [configure the motors](https://huggingface.co/docs/lerobot/so101#configure-the-motors) for the SO101 arms. 
- Follow this [installation guide](https://github.com/TheRobotStudio/SO-ARM100/tree/main/Optional/SO101_Wrist_Cam_Hex-Nut_Mount_32x32_UVC_Module) to add wrist cameras.
- If you have [3M gripper tape](https://www.amazon.com/gp/product/B0093CQPW8/ref=ppx_yo_dt_b_search_asin_title?ie=UTF8&psc=1), now it's time to wrap it on the fingers.

## 🤔 Configure Motors



> Since the official lerobot codebase currently doesn't support motor configuring besides the arm, we use [Bambot](https://bambot.org/) instead (works on Windows and Mac, Linux needs 'sudo chmod 666 /dev/ttyACM0' first).
>

- Connect the motor you want to configure (one-by-one) to a control board, and directly connect the board to your computer. 
- Navigate to [the motor configuration page of Bambot](https://bambot.org/feetech.js), establish the connection and scan for your servo motor.
  

- Rename the motor id following the instruction below.
  

- You need to configure two sets of motors for 2 motor control boards in addition to the SO101 arms:
    - one for **head** (motor ids: 7, 8)
    - and the other for **the wheel base** (motors ids: 7, 8, 9).
- Tips: write the numbers on motors with marker and distinguish motors for different boards (such as L1-L8 and R1-R9).

## 🛒 IKEA Cart

- Just in case you accidentally throw your manual away, [here it is](https://github.com/Vector-Wangel/XLeRobot/blob/main/others/Manuals_raskog_utility_cart.pdf).



## 🧑‍🦼‍➡ Wheel Base

> If you already have a Lekiwi base, detach the battery, servo mounts, etc. Base plate will only have 3 mounted motors with wheels (keep the wirings).
>



```{note}
Don't choose the wrong plate, each plate comes in a certain order.
```

- Mount the omni-wheels to the plate according to the figure above.
  - The specific motor id should be installed accordingly.
- Note that the connector of the omni-wheel needs 3x M4 screws.
- Wiring the motors regularly as the [tutorial](https://github.com/SIGRobotics-UIUC/LeKiwi/blob/main/Assembly.md#2-bottom-plate-assembly), after that instead of connecting the motor cable to the control board, use the extended wire/connector kit to extend the wire.



- Mount the top plate according to the figure above.
- Leave the motor cable hanging ,don't pull it out from the top plate just yet.



- Mount 3x connectors on the top plate according to the figure above.

```{tip}
Put the Lekiwi base with the connectors under the cart to see whether it can give enough pressure to the cart, with four wheels of the cart can still touch the ground. If not, try to modify the connectors' 3D model by slightly adjust the z-axis scale directly in the slicer software (keeping the xy-axis scale unchanged) and print them again.
```



```{tip}
Flip the cart over to do the assembly below.
```

- Now install the Lekiwi base with the connectors onto the bottom of the IKEA cart, with the thinner plate on the other side.
- Refer to the figure to find the desired assembly direction based on the motor index. 

```{note}
This new hardware version is compatible with the IKEA cart metal mesh, and all the 12 M3 screws should be able to fit in easily.
```



- Use needle-nose pliers to cut out the metal mesh at the corresponding holes in the top base, removing only the central "x" to maintain structural integrity. This creates openings for cable routing.
- Then, run the previously extended wire up through the cart from below.

## 🦾 Arm Base

### Top Base Assembly


- Easier assembly when the base is flipped over.

### Head Assembly



- It should be the same as the first two steps of [SO101 arm assembly](https://huggingface.co/docs/lerobot/so101#joint-1).

## 🧵 Wiring

```{important}
Complete all wiring and cable management for the top base and put the Raspberry Pi in its case before clamping the top base into the IKEA cart.
```



- Prepare the extended 5264 wire with the connector kit if you don't have one already.
- Use needle-nose pliers to cut out the metal mesh at for the upper two layers for cable routing, similar to the bottom layer previously. Choose the location as needed.
```{note}
When extending the 5264 wire yourself, be careful with the polarity—reversed connections will cause errors.
```
- Connect the extended 5264 **motor cable** from **the Lekiwi base** to **one of the SO101 arms** (this makes the base and the arm as Lekiwi).
- Connect the 2 **USB-C to USB-A** **data cables** from 2 **motor control board** to **Rasberry Pi** (2 USB-A slots left for the cameras).
- Connect all 3 **power cables**: 2 **USB-C to DC(12V)** from 2 **motor control board** and 1 **USB-C to USB-C** from **Rasberry Pi**, to the fast charging section of the power supply. Each slot provides up to 100W power when charging simultaneously, which is tested sufficient for 12V version operation.

### 🔋 Place the Battery 🛒

- Anywhere you like on the middle or lower level of the cart to maintain a low center of mass. The battery has an anti-slip bottom so it won't easily slide during normal operations.
- Maintain placed upright for safety.
- Just in case you also accidentally throw the battery manual away, [here it is](https://github.com/Vector-Wangel/XLeRobot/blob/main/others/Manual_Anker_SOLIX_C300_DC_Portable_Power_Station.pdf).

```{important}
In order to protect the motor control board, make sure to connect the power cables last. And always disconnect the power cables when plugging/unplugging other cables.
```
## 📸 Final Assembly

### Base into the Cart

```{important}
Complete all wiring and cable management for the top base and put the Raspberry Pi in its case before clamping the top base into the IKEA cart.
```



- Be careful not to break the case when you jam the IKEA cart edge into the case socket.
- For easier testing, the SO101 arms clamp directly onto the cart. Position the [arm bases](https://github.com/Vector-Wangel/XLeRobot/blob/main/3D_Models/3D_models_for_printing/XLeRobot_special/SO_5DOF_ARM100_Assemblybases.stl) at the two corners of the cart's top layer, then secure with clamps.
- Don't forget to put the bambulab filament cardboard spool inside to provide stable structural support if you have one.

After these steps, the XLeRobot should be physically well-built and ready to do some chores.





```{important}
Once XLeRobot is fully assembled, do not push it around like the IKEA cart, as this can damage the motor gears. Instead, lift the robot (~12kg) whenever you need to move it manually.
```
```{note}
Current form of the wheel connector is not strong, occasionally rescrewing the center screw may be needed.
```
### Optional Visual Upgrades

For better visual outlook, you can wear these parts to XLeRobot if you like. 



- **Shells** for the Control board and the first joint for better protection and visual.
  - You may need to take off the hand camera first before wearing the 2nd shell onto the arm.
- Sports sleeves to hide the cables and make XLeRobot more sleek.
  


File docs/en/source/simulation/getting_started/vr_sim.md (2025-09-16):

# XLeVR Tutorial

This guide explains how to use VR devices (currently Meta Quest3) for interactive control in XLeRobot simulation environments. It covers environment setup, dependencies, VR data flow, running demos, troubleshooting, and advanced usage.

---

## 1. Environment Setup

### 1.1 Dependencies

Ensure you have the following installed:

- Python 3.7+
- [ManiSkill](https://github.com/haosulab/ManiSkill)
- [XLeVR](../../../XLeVR/README.md) (included in this repo)

Example installation:

```bash
# Install ManiSkill and dependencies
pip install mani-skill
# Install XLeVR dependencies
cd XLeVR
pip install -r requirements.txt
```

---

## 2. VR Integration & Data Flow

### 2.1 VR Data Flow Overview

XLeVR uses a WebSocket server to stream real-time data from VR headsets and controllers, and provides a web UI via HTTPS for monitoring. The core data structure is `ControlGoal`, which includes position, orientation, button states, and more.

#### ControlGoal Main Fields

- `arm`: Device type ("left", "right", "headset")
- `target_position`: 3D coordinates (numpy array)
- `wrist_roll_deg`/`wrist_flex_deg`: Wrist roll/pitch angles
- `gripper_closed`: Whether the gripper is closed
- `metadata`: Extra info (trigger, thumbstick, etc)

### 2.2 Start the VR Monitor Service

From the `XLeVR` directory, run:

```bash
python vr_monitor.py
```

- The terminal will show an HTTPS address (e.g., `https://<your-ip>:8443`). Open this in your VR headset browser to see real-time control data.
- You can also copy `vr_monitor.py` to another project folder and edit the `XLEVR_PATH` variable at the top of the script.

---

## 3. Using VR Control in Simulation

### 3.1 Run the VR Control Demo

For ManiSkill environments, run:

```bash
python -m mani_skill.examples.demo_ctrl_action_ee_VR \
 -e "ReplicaCAD_SceneManipulation-v1" \
 --render-mode="human" \
 --shader="rt-fast" \
 -c "pd_joint_delta_pos_dual_arm" \
 -r "xlerobot"

```

- `-e` sets the environment (e.g., `ReplicaCAD_SceneManipulation-v1`, AI2THOR, Robocasa, etc.)
- `--render-mode` should be `human` for real-time visualization
- `-c` sets the control mode

### 3.2 Control Instructions

- **Move controllers**: Control the end-effector positions of both arms
- **Trigger**: Open/close the gripper
- **Thumbstick**: Move/rotate the robot base
- **Headset**: Used for viewpoint/pose data
- **Web UI**: Shows real-time device status and data

---

## 5. Troubleshooting

### 5.1 Startup Errors

- Check that `XLEVR_PATH` is set correctly
- If certificates (`cert.pem`/`key.pem`) are missing, generate them or disable HTTPS

### 5.2 No VR Data

- Make sure the VR headset is connected and accessing the correct HTTPS address
- Check firewall/port settings

### 5.3 Control Issues

- Check VR device drivers and firmware
- Ensure `vr_monitor.py` is running

---

## 6. Advanced Usage

### 6.1 Access VR Data in Code

You can access VR control goals directly in Python:

```python
from mani_skill.examples.vr_monitor import VRMonitor

monitor = VRMonitor()
monitor.initialize()
left_goal = monitor.get_left_goal_nowait()
right_goal = monitor.get_right_goal_nowait()
# left_goal/right_goal are ControlGoal objects
```

### 6.2 Data Structure Reference

See [XLeVR/README.md](../../../XLeVR/README.md) or the `vr_monitor.py` code for details.

---

## 7. References

- [ManiSkill Documentation](https://maniskill.readthedocs.io/en/latest/user_guide/datasets/scenes.html)
- [Oculus Reader Documentation](https://github.com/rail-berkeley/oculus_reader)
- [XLeVR/telegrip](https://github.com/DipFlip/telegrip)

---

For further questions, please open an issue or check the code comments.

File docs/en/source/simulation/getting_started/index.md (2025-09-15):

# Get Started

### Prerequisites

- Ubuntu operating system
- Basic familiarity with terminal commands
- [Miniconda](https://docs.anaconda.com/free/miniconda/index.html) (recommended)

### Installation

#### 1. Create a Conda Environment

If you already have a `lerobot` conda environment, you can use that. Otherwise, create a new environment:

```bash
conda create -y -n lerobot python=3.11
conda activate lerobot

```

> Note: It's recommended to have ManiSkill and lerobot code in the same environment for future sim2real deployment.
> 

#### 2. Install ManiSkill

Follow the [official installation instructions](https://maniskill.readthedocs.io/en/latest/user_guide/getting_started/installation.html) for ManiSkill.

```bash
# Basic installation
pip install mani-skill

# Download scene dataset
python -m mani_skill.utils.download_asset "ReplicaCAD"

```

If the dataset downloading goes wrong, you can directly download the dataset from [this google drive link](https://drive.google.com/file/d/1mqImztNX1LYZFBzt9z895C814RsyGe4N/view?usp=sharing). And then folder contents should go to

```bash
~/.maniskill/data/scene_datasets/replica_cad_dataset

```

Familiarize yourself with ManiSkill using the [quickstart guide](https://maniskill.readthedocs.io/en/latest/user_guide/getting_started/quickstart.html) and [demo scripts](https://maniskill.readthedocs.io/en/latest/user_guide/getting_started/quickstart.html). 

Try this command to test whether you have successfully installed Maniskill:

```{note}
Change shader="rt-fast" to "default" for faster rendering or if your computer doesn't support ray-tracing rendering.
```

```bash
python -m mani_skill.examples.demo_random_action -e "ReplicaCAD_SceneManipulation-v1" \
  --render-mode="human" --shader="rt-fast"

```

And you should be looking at something like this:



#### 3. Additional Dependencies

We use **pygame** to read keyboard input and show the control panel in real time, and **Rerun** to visualize and collect camera data.

```bash
pip install pygame
pip install rerun-sdk
```

#### 4. Put XLeRobot Files to Maniskill

```{note}
We are expecting Maniskill to offer official support for XLeRobot soon, after that this step can be skipped.
```

Navigate to the ManiSkill package folder in your conda environment:

```bash
cd ~/miniconda3/envs/lerobot/lib/python3.10/site-packages/mani_skill
```

Put the XLeRobot files into Maniskill folders:

1. Download the [**XLeRobot Robot files** here](https://github.com/Vector-Wangel/XLeRobot/tree/main/simulation/Maniskill):
2. Put the files in /agents/robots, /assets/robots, and /envs/scenes:
   
   
   

   

   After putting XLeRobot robot description files to /agents/robots, add this line in /agents/robots/init.py
   
    
4. Add the control codes to /examples:
    
    

5. Modify utils/scene_builder/replicacad/scenebulider.py: For new robot ids, you need to add them to ReplicaCAD scene first.

   

#### Get Moving

```{note}
Change shader="default" to "rt-fast" for photo-realistic ray-tracing rendering (but slower).
```

##### Joint Control

```bash
python -m mani_skill.examples.demo_ctrl_action -e "ReplicaCAD_SceneManipulation-v1" -r "xlerobot"  --render-mode="human" --shader="default" -c "pd_joint_delta_pos_dual_arm"

```


##### End Effector Control 

Original dual-arm version:

```bash
python -m mani_skill.examples.demo_ctrl_action_ee_keyboard -e "ReplicaCAD_SceneManipulation-v1" -r "xlerobot"  --render-mode="human" --shader="default" -c "pd_joint_delta_pos_dual_arm"

```

Single-arm version:

```
python -m mani_skill.examples.demo_ctrl_action_ee_keyboard_single -e "ReplicaCAD_SceneManipulation-v1" -r "xlerobot_single"  --render-mode="human" --shader="default" -c "pd_joint_delta_pos"
```

With Camera Visualization via Rerun:

```bash
python -m mani_skill.examples.demo_ctrl_action_ee_cam_rerun -e "ReplicaCAD_SceneManipulation-v1" -r "xlerobot"  --render-mode="human" --shader="default" -c "pd_joint_delta_pos_dual_arm"

```



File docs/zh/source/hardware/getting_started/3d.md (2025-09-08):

# 🖨️ 3D打印



## [在此下载3D模型](https://github.com/Vector-Wangel/XLeRobot/tree/main/hardware)

## 🤔 打印前准备 

> 我们假设你有使用消费级3D打印机(BambuLab、Prusa等)的基本经验。这意味着你知道如何正确地使用PLA耗材3D打印STL文件，并熟悉重新定向零件、添加支撑、调整填充率和修改打印速度，以在材料强度、效率和模型细节质量之间达到理想的平衡。
> 
- 更详细的信息，你可以查看[Lekiwi](https://github.com/SIGRobotics-UIUC/LeKiwi/blob/main/3DPrinting.md)和[SO101手臂](https://github.com/TheRobotStudio/SO-ARM100#printing-the-parts)的3D打印说明。
- XLeRobot演示视频和图片中显示的所有3D打印零件都是用**BambuLab A1使用BambuLab PLA哑光黑色**打印的。
- 你也可以使用具有更好机械性能的耗材，如[**PETG HF、PLA CF**](https://us.store.bambulab.com/products/pla-cf)、[**BambuLab Tough PLA**](https://us.store.bambulab.com/products/pla-tough-upgrade)等，以增强手臂的强度。
- 对于潮湿环境，建议在打印前将PLA在45°C下烘干8小时。

### 💰 成本考虑

* **自有打印机** (推荐): 所有零件都可以在[BambuLab A1 (~$350 USD)](https://us.store.bambulab.com/products/a1)等消费级3D打印机上打印，你可以轻松制作更多并修改自己的零件。
* **耗材成本**: 所需PLA耗材约15-25美元
* **服务打印**: 如果使用3D打印服务，包含服务费在内的总成本通常不超过50美元

```{note}
你也可以参考([Lekiwi](https://github.com/SIGRobotics-UIUC/LeKiwi/blob/main/3DPrinting.md)和[SO101手臂](https://github.com/TheRobotStudio/SO-ARM100#printing-the-parts))的说明以及本教程。
```

```{note}
注意[3D打印.3mf文件](https://github.com/Vector-Wangel/XLeRobot/tree/main/hardware)仅用于存储模型。强烈建议在切片软件中自己放置、定向和添加支撑，以确保最佳打印质量。
```

## 🖖 SO101手臂



- 对于XLeRobot，你只需要打印两个跟随手臂。[主导手臂](https://github.com/TheRobotStudio/SO-ARM100/tree/main?tab=readme-ov-file#printing-the-parts)只有在你计划用主从关节控制同时操作双臂时才需要。

- 打印前，请在切片软件中重新排列此stl文件的布局，以获得最佳打印体验。

- 📷相机: 你可以在这里找到[手腕相机支架的安装指南](https://github.com/TheRobotStudio/SO-ARM100/tree/main/Optional/SO101_Wrist_Cam_Hex-Nut_Mount_32x32_UVC_Module)。

- 🫱软抓手: .3mf文件包含需要用TPU95A打印的软鳍指。如果你想要原始SO101手指，只需下载原始[SO101.stl](https://github.com/Vector-Wangel/XLeRobot/blob/main/hardware/Ender_Follower_SO101.stl)文件。
- d2e57534a9e55a3d4dc0d644242cd044

## 🦾 手臂底座

### 📦 手臂底座



- 连接2个手臂底座以实现标准化的手臂间距。
- 中间存储外壳用于计算设备和线缆管理。
- 你可以插入使用过的Bambulab耗材纸质线轴以提供额外的结构支撑。
- 可选零件: 控制板和第一个关节的外壳，用于更好的保护和视觉效果。



### 🐼 颈部和头部



- 头部基于SO101的前两个关节设计。与相同电机兼容。
- .3mf文件包含2个版本的单RGB头部相机连接器和外壳，一个用于网络摄像头和realsense，另一个用于与手部相机相同的更便宜的相机。

- 
- 你可以使用任何你喜欢的头部相机，只需对最后的安装连杆进行小幅修改。步骤文件可在[这里](https://github.com/Vector-Wangel/XLeRobot/tree/main/hardware/step)获得，供你调整。
- 中空颈部用于节省耗材和线缆管理。

## 🧑‍🦼‍➡️ 轮式底座



- 通过在切片软件中修改底座连接器的z轴比例(同时保持xy轴比例)来调整其高度，以确保底座上的3个全向轮和4个宜家推车轮子之间的压力分布均匀。
- 
- 调整底座连接器的替代方案: 只需打印下面的垫圈并将其插入宜家推车，以获得最佳底座支撑。
- 

### 💰 成本考虑

* **自有打印机** (推荐): 所有零件都可以在Bambu Lab A1 (~$400 USD)等消费级3D打印机上打印
* **耗材成本**: 所需PLA耗材约15-25美元
* **服务打印**: 如果使用3D打印服务，包含服务费在内的总成本通常不超过50美元

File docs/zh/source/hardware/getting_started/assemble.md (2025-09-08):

# ⚒️ 组装



> 预计组装时间：从零开始：2-4小时；有已组装的SO100/SO101手臂：1-2小时
> 
```{tip}
如果你宁愿跳过拧螺丝的乐趣，你也可以购买SO101手臂的[预组装套件](https://github.com/TheRobotStudio/SO-ARM100#kits)。
```

## 🦾 SO101手臂



> 如果你已经有2个配置了电机的组装好的SO101手臂，请跳过。
>

- 按照[SO101逐步组装说明](https://huggingface.co/docs/lerobot/so101)构建2个SO101手臂，制作2个相同的跟随手臂，配备2套电机(之前都索引为1-6)用于2个控制板。
- 然后继续为SO101手臂[配置电机](https://huggingface.co/docs/lerobot/so101#configure-the-motors)。
- 按照这个[安装指南](https://github.com/TheRobotStudio/SO-ARM100/tree/main/Optional/SO101_Wrist_Cam_Hex-Nut_Mount_32x32_UVC_Module)添加手腕相机。
- 如果你有[3M抓握胶带](https://www.amazon.com/gp/product/B0093CQPW8/ref=ppx_yo_dt_b_search_asin_title?ie=UTF8&psc=1)，现在是时候将其包裹在手指上了。

## 🤔 配置电机



> 由于官方lerobot代码库目前不支持除手臂外的电机配置，我们使用[Bambot](https://bambot.org/)代替(在Windows和Mac上工作，Linux需要先运行'sudo chmod 666 /dev/ttyACM0')。
>

- 将你想要配置的电机(逐个)连接到控制板，并直接将板子连接到你的计算机。
- 导航到[Bambot的电机配置页面](https://bambot.org/feetech.js)，建立连接并扫描你的舵机电机。
  

- 按照下面的说明重命名电机id。
  

- 除了SO101手臂外，你还需要为2个电机控制板配置两套电机：
    - 一套用于**头部**(电机id：7, 8)
    - 另一套用于**轮式底座**(电机id：7, 8, 9)。
- 提示：用记号笔在电机上写数字，并区分不同板子的电机(如L1-L8和R1-R9)。

## 🛒 宜家推车

- 万一你意外扔掉了手册，[这里有一份](https://github.com/Vector-Wangel/XLeRobot/blob/main/others/Manuals_raskog_utility_cart.pdf)。



## 🧑‍🦼‍➡ 轮式底座

> 如果你已经有一个Lekiwi底座，请拆下电池、舵机支架等。底板只需安装3个带轮子的电机(保留接线)。
>



```{note}
不要选错板子，每个板子都有特定的顺序。
```

- 根据上图将全向轮安装到板子上。
  - 应相应安装特定的电机id。
- 注意全向轮的连接器需要3个M4螺丝。
- 按照[教程](https://github.com/SIGRobotics-UIUC/LeKiwi/blob/main/Assembly.md#2-bottom-plate-assembly)正常接线电机，之后不要将电机线缆连接到控制板，而是使用延长线/连接器套件来延长线缆。



- 根据上图安装顶板。
- 让电机线缆悬挂，暂时不要从顶板拉出来。



- 根据上图在顶板上安装3个连接器。

```{tip}
将带连接器的Lekiwi底座放在推车下方，看看是否能给推车足够的压力，推车的四个轮子仍能接触地面。如果不能，尝试通过在切片软件中直接稍微调整z轴比例(保持xy轴比例不变)来修改连接器的3D模型并重新打印。
```



```{tip}
翻转推车进行下面的组装。
```

- 现在将带连接器的Lekiwi底座安装到宜家推车的底部，较薄的板子在另一侧。
- 参考图片根据电机索引找到所需的组装方向。

```{note}
这个新硬件版本与宜家推车金属网格兼容，所有12个M3螺丝都应该能够轻松装入。
```



- 使用尖嘴钳在顶部底座的相应孔位切割金属网格，只移除中央的"x"以保持结构完整性。这为线缆布线创建开口。
- 然后，将之前延长的线缆从下方穿过推车向上布线。

## 🦾 手臂底座

### 顶部底座组装


- 当底座翻转过来时组装更容易。

### 头部组装



- 这应该与[SO101手臂组装](https://huggingface.co/docs/lerobot/so101#joint-1)的前两个步骤相同。

## 🧵 接线

```{important}
在将顶部底座夹到宜家推车之前，完成顶部底座的所有接线和线缆管理，并将树莓派放入其外壳中。
```



- 如果你还没有，请准备带连接器套件的延长5264线缆。
- 使用尖嘴钳为上层两层切割金属网格进行线缆布线，类似于之前的底层。根据需要选择位置。
```{note}
当你自己延长5264线缆时，要小心极性——反向连接会导致错误。
```
- 将来自**Lekiwi底座**的延长5264**电机线缆**连接到**一个SO101手臂**(这使底座和手臂成为Lekiwi)。
- 将2根**USB-C转USB-A****数据线缆**从2个**电机控制板**连接到**树莓派**(剩下2个USB-A插槽用于相机)。
- 连接所有3根**电源线缆**：2根**USB-C转DC(12V)**从2个**电机控制板**和1根**USB-C转USB-C**从**树莓派**，连接到电源的快充部分。每个插槽在同时充电时提供高达100W功率，经测试足以支持12V版本运行。

### 🔋 放置电池 🛒

- 放在推车中层或下层的任何位置以保持低重心。电池有防滑底部，在正常操作中不易滑动。
- 为了安全保持直立放置。
- 万一你也意外扔掉了电池手册，[这里有一份](https://github.com/Vector-Wangel/XLeRobot/blob/main/others/Manual_Anker_SOLIX_C300_DC_Portable_Power_Station.pdf)。

```{important}
为了保护电机控制板，确保最后连接电源线缆。在插拔其他线缆时始终断开电源线缆。
```

## 📸 最终组装

### 底座装入推车

```{important}
在将顶部底座夹到宜家推车之前，完成顶部底座的所有接线和线缆管理，并将树莓派放入其外壳中。
```



- 当你将宜家推车边缘塞入外壳插座时要小心不要弄坏外壳。
- 为了更容易测试，SO101手臂直接夹在推车上。将[手臂底座](https://github.com/Vector-Wangel/XLeRobot/blob/main/3D_Models/3D_models_for_printing/XLeRobot_special/SO_5DOF_ARM100_Assemblybases.stl)定位在推车顶层的两个角落，然后用夹子固定。
- 如果你有bambulab耗材纸质线轴，不要忘记将其放在里面以提供稳定的结构支撑。



完成这些步骤后，XLeRobot应该在物理上组装良好，准备做一些家务。





```{important}
XLeRobot完全组装后，不要像宜家推车那样推着它到处走，因为这可能损坏电机齿轮。相反，当你需要手动移动时，请抬起机器人(~12kg)。
```
```{note}
当前形式的轮连接器不够坚固，偶尔可能需要重新拧紧中心螺丝。
```
### 可选视觉升级

为了更好的视觉效果，如果您喜欢，可以为XLeRobot穿戴这些零件。



- **外壳**用于控制板和第一个关节，提供更好的保护和视觉效果。
  - 在将第二个外壳穿到手臂上之前，您可能需要先取下手部相机。
- 运动袖套用于隐藏线缆，使XLeRobot更加时尚。
  


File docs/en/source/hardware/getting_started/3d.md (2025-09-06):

# 🖨️ 3D printing



## [Download the 3D Models Here](https://github.com/Vector-Wangel/XLeRobot/tree/main/hardware)

## 🤔 Before Printing 

> We assume you have basic experience with consumer-level 3D printers (BambuLab, Prusa, etc.). This means you know how to properly 3D print STL files with PLA filaments and are familiar with reorienting parts, adding supports, adjusting infill, and modifying print speed to achieve your desired balance of material strength, efficiency, and model detail quality.
> 
- For more detailed information, you can check out the 3D printing instructions for [Lekiwi](https://github.com/SIGRobotics-UIUC/LeKiwi/blob/main/3DPrinting.md) and [SO101 Arm](https://github.com/TheRobotStudio/SO-ARM100#printing-the-parts).
- All the 3D printed parts shown in the demo videos and pictures of XLeRobot were printed with a **BambuLab A1 using BambuLab PLA Matte Black**.
- You can also use filaments with better mechanical properties, such as [**PETG HF, PLA CF**](https://us.store.bambulab.com/products/pla-cf), [**BambuLab Tough PLA**](https://us.store.bambulab.com/products/pla-tough-upgrade), etc., to enhance the arm's strength.
- Drying PLA is recommended for humid environments at 45°C for 8 hours before printing.

### 💰 Cost Considerations

* **Your Own printer** (Recommended): Everything can be printed on consumer 3D printers like [BambuLab A1 (~$350 USD)](https://us.store.bambulab.com/products/a1), and you can easily make more and modify your own parts.
* **Filament cost**: Approximately $15–25 USD for the required PLA filament
* **Service printing**: If using a 3D printing service, the total cost is typically under $50 USD, including service fees

```{note}
You can also refer to the instructions of ([Lekiwi](https://github.com/SIGRobotics-UIUC/LeKiwi/blob/main/3DPrinting.md) and [SO101 Arm](https://github.com/TheRobotStudio/SO-ARM100#printing-the-parts)) along with this tutorial.
```

```{note}
Note that the [3D Printing .3mf files](https://github.com/Vector-Wangel/XLeRobot/tree/main/hardware) are only to store the models. It’s highly suggested to place, orient, and add supports yourself in the slicing software to ensure the best printing quality.
```

## 🖖 SO101 Arms



- For XLeRobot, you only need to print two follower arms. The [leader arm](https://github.com/TheRobotStudio/SO-ARM100/tree/main?tab=readme-ov-file#printing-the-parts) is only necessary if you plan to operate the dual arms simultaneously with leader-follower joint control. 

- Before printing, rearrange the layout of this stl file in the slicer software for your best printing experience.

- 📷Camera: You can find the installation guide for [the Wrist Camera Mount here](https://github.com/TheRobotStudio/SO-ARM100/tree/main/Optional/SO101_Wrist_Cam_Hex-Nut_Mount_32x32_UVC_Module).

- 🫱Soft Gripper: The .3mf file contains soft finray fingers that need to be printed with TPU95A. If you want original SO101 finger, just download the original [SO101.stl](https://github.com/Vector-Wangel/XLeRobot/blob/main/hardware/Ender_Follower_SO101.stl) file.
- d2e57534a9e55a3d4dc0d644242cd044

## 🦾 Arm Base

### 📦 Arm Base



- 2 arm bases are connected for standardized arm spacing.
- A middle storage shell for computational devices and cable management.
- You can insert a used Bambulab filament cardboard spool for additional structural support.
- Optional parts: Shells for the Control board and the first joint for better protection and visual.



### 🐼 Neck and head



- Head designed based on the first two links of SO101. Compatible with the same motor.
- The .3mf file contains 2 version of the single RGB head camera connector and shell, one for webcam & realsense, the other for the cheaper camera same as the hand camera. 

- 
- You can use any head camera you like, just make a little modification to the last mounting link. The step files are available [HERE](https://github.com/Vector-Wangel/XLeRobot/tree/main/hardware/step) for your adjustment. 
- Hollow neck for filament saving and cable management.

## 🧑‍🦼‍➡️ Wheel Base



- Adjust the height of the base connector by modifying its z-axis scale in your slicer software (while maintaining the xy-axis scale) to ensure even pressure distribution between the 3 omni-wheels on the base and 4 IKEA cart wheels.
- 
- Alternative to adjusting the base connector: just print the washers below and insert them into the IKEA cart for the best base support.
- 

### 💰 Cost Considerations

* **Own printer** (Recommended): Everything can be printed on consumer 3D printers like the Bambu Lab A1 (~$400 USD)
* **Filament cost**: Approximately $15–25 USD for the required PLA filament
* **Service printing**: If using a 3D printing service, the total cost is typically under $50 USD, including service fees

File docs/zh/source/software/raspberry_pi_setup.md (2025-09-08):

# XLeRobot树莓派设置指南

本指南提供了为XLeRobot移动底座版本设置树莓派的详细说明。

## 先决条件

- 树莓派(推荐: Pi 4或更新版本)
- MicroSD卡(推荐32GB或更大)
- 带SD卡读卡器的计算机
- 网络连接(WiFi或以太网)

## 1. 安装操作系统

### 下载树莓派操作系统
1. 访问[官方树莓派网站](https://www.raspberrypi.org/software/)
2. 下载树莓派镜像工具
3. 下载树莓派操作系统(推荐: 带桌面的树莓派操作系统)

### 将操作系统刷写到SD卡
1. 将microSD卡插入计算机
2. 打开树莓派镜像工具
3. 选择下载的操作系统镜像
4. 选择您的SD卡
5. 点击"写入"刷写操作系统

### 初始设置
1. 将SD卡插入树莓派
2. 连接键盘、鼠标和显示器
3. 启动树莓派
4. 按照初始设置向导：
   - 设置国家、语言和时区
   - 创建用户账户和密码
   - 连接到WiFi网络
   - 更新系统包

```{note}
主机名选项定义您的树莓派使用mDNS向网络广播的主机名。当您将树莓派连接到网络时，网络上的其他设备可以使用`<hostname>`.local或`<hostname>`.lan与您的计算机通信。

用户名和密码选项定义您树莓派上管理员用户账户的用户名和密码。

无线局域网选项允许您输入无线网络的SSID(名称)和密码。如果您的网络不公开广播SSID，您应该启用"隐藏SSID"设置。默认情况下，镜像工具使用您当前所在的国家作为"无线局域网国家"。此设置控制您的树莓派使用的Wi-Fi广播频率。如果您计划运行无头树莓派，请输入无线局域网选项的凭据。

```

   树莓派操作系统自定义

## 2. 设置VNC远程桌面

### 启用VNC服务器
1. 在树莓派上打开终端
2. 运行配置工具：
```bash
sudo raspi-config
```
3. 导航到"接口选项" → "VNC" → "启用"
4. 重启系统

### 替代方案：通过命令行启用VNC
```bash
sudo systemctl enable vncserver-x11-serviced
sudo systemctl start vncserver-x11-serviced
```

### 在您的PC上安装VNC查看器
1. 下载[RealVNC查看器](https://www.realvnc.com/en/connect/download/viewer/)
2. 安装并启动VNC查看器
3. 使用`<hostname>`.local或`<hostname>`.lan连接，对我来说是XLerobot.local **(确保这些设备在同一网络中)**
4. 使用您的Pi的用户名和密码进行身份验证



有关详细的VNC设置说明，请参考[此综合指南](https://www.raspberrypi.com/documentation/computers/remote-access.html#vnc)。

## 3. 系统更新和依赖项

### 更新系统包
```bash
sudo apt update
sudo apt upgrade -y
```

### 安装基本包
```bash
sudo apt install -y python3-pip git curl wget
```

## 4. 启用SSH访问(可选)

### 启用SSH
```bash
sudo systemctl enable ssh
sudo systemctl start ssh
```

### 查找您的Pi的IP地址
```bash
hostname -I
```

### 从您的PC连接
```bash
ssh pi@<your-pi-ip-address>
```

## 5. 安装XLeRobot软件

按照官方[软件安装说明](https://huggingface.co/docs/lerobot/installation#install-lerobot-)获取详细步骤。

并复制[配置文件](https://xlerobot.readthedocs.io/en/latest/index.html)。

## 下一步

完成此设置后，您可以像笔记本电脑一样运行代码：



## 其他资源

- [官方树莓派文档](https://www.raspberrypi.org/documentation/)
- [RealVNC设置指南](https://pidoc.cn/docs/computers/getting-started)
- [XLeRobot GitHub仓库](https://xlerobot.readthedocs.io/en/latest/index.html)

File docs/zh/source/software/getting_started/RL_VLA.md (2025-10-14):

## 强化学习(RL)

您可以先尝试[lerobot-sim2real (by Stone Tao)](https://github.com/StoneT2000/lerobot-sim2real)与Maniskill，或[huggingface官方HIL-SERL教程](https://huggingface.co/docs/lerobot/hilserl)在单SO101手臂上。完整XLeRobot RL的官方代码即将推出。下面的演示显示了[lerobot-sim2real](https://github.com/StoneT2000/lerobot-sim2real)的实现，对摄像头方向和仿真对象分布进行了小幅修改。

<video width="100%" controls>
  <source src="https://vector-wangel.github.io/XLeRobot-assets/videos/Real_demos/sim2real_2.mp4" type="video/mp4">
  Your browser does not support the video tag.
</video>

## VLA

您可以先按照[huggingface官方VLA教程](https://huggingface.co/docs/lerobot/smolvla)在单SO101手臂上。完整XLeRobot VLA的官方代码即将推出。

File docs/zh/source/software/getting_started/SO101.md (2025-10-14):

## SO100/SO101手臂控制示例

### 1. 键盘关节控制

使用直接关节角度操作的最基本控制方法。运行`0_so100_keyboard_joint_control.py`使用键盘输入手动控制各个关节位置。这提供对每个关节运动的直接访问，无需逆运动学计算。

### 2. 键盘末端执行器控制

使用逆运动学在笛卡尔空间中移动末端执行器的高级控制。运行`1_so100_keyboard_ee_control.py`进行直观控制，其中键盘输入控制末端执行器位置(X、Y坐标)而不是单个关节。

<video width="100%" controls>
  <source src="https://vector-wangel.github.io/XLeRobot-assets/videos/Real_demos/keyboard_teleop.mp4" type="video/mp4">
  Your browser does not support the video tag.
</video>

### 3. 双臂键盘控制

通过不同串口(/dev/ttyACM0和/dev/ttyACM1)连接的两个SO100手臂的同时控制。运行`2_dual_so100_keyboard_ee_control.py`进行协调的双臂操作，每个手臂有单独的键盘映射。

### 4. 基于视觉的物体跟踪

YOLO驱动的物体检测和跟踪系统。运行`3_so100_yolo_ee_control.py`使机器人能够使用计算机视觉自动跟踪检测到的物体(如瓶子)。此演示无需训练，结合了实时物体检测和末端执行器控制。

您可以查看[Ultralytics官方网站](https://docs.ultralytics.com/models/)以极其简单的方式尝试各种不同的视觉相关模型和应用。

<video width="100%" controls>
  <source src="https://vector-wangel.github.io/XLeRobot-assets/videos/Real_demos/yolo.mp4" type="video/mp4">
  Your browser does not support the video tag.
</video>

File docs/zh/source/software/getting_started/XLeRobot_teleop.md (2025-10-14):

### XLeRobot遥操作

### 常见问题

- 如果您使用Ubuntu，请确保在插入电机控制板后运行`sudo chmod 666 /dev/ttyACM0`和`sudo chmod 666 /dev/ttyACM1`。
- 然后运行`python lerobot/find_port.py`检查控制板ID。然后在以下位置相应更改名称：
- 
- 如果您在`sudo chmod ...`后遇到未检测到任何电机的错误，请尝试重新插入电源线。
- 如果您遇到`需要9个电机，但检测到8个`的错误，您需要交换上图两个控制板的ID。

### 5. 键盘遥操作

包括双臂、移动底座和头部电机的完整系统控制。运行[4_xlerobot_teleop_keyboard.py](https://github.com/Vector-Wangel/XLeRobot/blob/main/software/examples/4_xlerobot_teleop_keyboard.py)进行基于键盘的整个XLeRobot系统综合遥操作，左臂、右臂、底座移动和头部控制有单独的按键映射。

### 6. Xbox控制器遥操作  

完整XLeRobot系统的直观游戏手柄控制。运行[5_xlerobot_teleop_xbox.py](https://github.com/Vector-Wangel/XLeRobot/blob/main/software/examples/5_xlerobot_teleop_xbox.py)进行基于Xbox控制器的遥操作，具有人体工学摇杆和扳机映射，实现自然的人机交互。

<video width="100%" controls>
  <source src="https://vector-wangel.github.io/XLeRobot-assets/videos/Real_demos/xlerobot_025_001.mp4" type="video/mp4">
  Your browser does not support the video tag.
</video>

### 7. Switch Joycon遥操作

- Joycon遥操作基于[joycon-robotics (by box2ai)](https://github.com/box2ai-robotics/joycon-robotics)仓库构建。所以首先您需要git clone该仓库并按照其指南安装(包括安装外部包和make install)。然后直接用[我的修改版本](https://github.com/Vector-Wangel/XLeRobot/tree/main/software/joyconrobotics)替换所有代码。

- 根据我自己的经验，建议也运行`sudo apt install joycond`和`sudo systemctl enable --now joycond`以确保更好的蓝牙连接。

- 将您的Joy-Con置于配对模式：按住Joy-Con侧面的小同步按钮(SR和SL按钮之间)，直到指示灯(单点)开始闪烁
- 打开蓝牙设置：转到设置→蓝牙(或从终端使用bluetoothctl)。
  - 在设备列表中查找"Joy-Con (L)"或"Joy-Con (R)"
  - 点击配对每一个，然后您应该看到指示灯(多点)闪烁
  - 然后按下：左：L(上扳机) + 右：R(上扳机)一起，您应该看到两个joycon上只有第一个指示灯亮起，表示连接成功。
- 您可以先运行测试文件`joycon_test_read.py`以确保连接成功。
- 然后您可以运行`6_so100_joycon_ee_control.py`进行单SO101手臂控制(只需要一个joycon)，如以下所示，以及`7_xlerobot_teleop_joycon.py`进行完整的XLeRobot遥操作(这是我在0.3.0演示中用于大部分家务遥操作的内容)。

### 8. VR遥操作

您可以先尝试[在仿真中用VR控制XLeRobot](https://xlerobot.readthedocs.io/en/latest/simulation/getting_started/vr_sim.html)。真实机器人的VR遥操作官方代码即将推出。

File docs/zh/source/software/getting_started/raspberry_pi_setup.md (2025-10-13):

# XLeRobot树莓派设置指南

本指南提供了为XLeRobot移动底座版本设置树莓派的详细说明。

## 先决条件

- 树莓派(推荐: Pi 4或更新版本)
- MicroSD卡(推荐32GB或更大)
- 带SD卡读卡器的计算机
- 网络连接(WiFi或以太网)

## 1. 安装操作系统

### 下载树莓派操作系统
1. 访问[官方树莓派网站](https://www.raspberrypi.org/software/)
2. 下载树莓派镜像工具
3. 下载树莓派操作系统(推荐: 带桌面的树莓派操作系统)

### 将操作系统刷写到SD卡
1. 将microSD卡插入计算机
2. 打开树莓派镜像工具
3. 选择下载的操作系统镜像
4. 选择您的SD卡
5. 点击"写入"刷写操作系统

### 初始设置
1. 将SD卡插入树莓派
2. 连接键盘、鼠标和显示器
3. 启动树莓派
4. 按照初始设置向导：
   - 设置国家、语言和时区
   - 创建用户账户和密码
   - 连接到WiFi网络
   - 更新系统包

```{note}
主机名选项定义您的树莓派使用mDNS向网络广播的主机名。当您将树莓派连接到网络时，网络上的其他设备可以使用`<hostname>`.local或`<hostname>`.lan与您的计算机通信。

用户名和密码选项定义您树莓派上管理员用户账户的用户名和密码。

无线局域网选项允许您输入无线网络的SSID(名称)和密码。如果您的网络不公开广播SSID，您应该启用"隐藏SSID"设置。默认情况下，镜像工具使用您当前所在的国家作为"无线局域网国家"。此设置控制您的树莓派使用的Wi-Fi广播频率。如果您计划运行无头树莓派，请输入无线局域网选项的凭据。

```

   树莓派操作系统自定义

## 2. 设置VNC远程桌面

### 启用VNC服务器
1. 在树莓派上打开终端
2. 运行配置工具：
```bash
sudo raspi-config
```
3. 导航到"接口选项" → "VNC" → "启用"
4. 重启系统

### 替代方案：通过命令行启用VNC
```bash
sudo systemctl enable vncserver-x11-serviced
sudo systemctl start vncserver-x11-serviced
```

### 在您的PC上安装VNC查看器
1. 下载[RealVNC查看器](https://www.realvnc.com/en/connect/download/viewer/)
2. 安装并启动VNC查看器
3. 使用`<hostname>`.local或`<hostname>`.lan连接，对我来说是XLerobot.local **(确保这些设备在同一网络中)**
4. 使用您的Pi的用户名和密码进行身份验证



有关详细的VNC设置说明，请参考[此综合指南](https://www.raspberrypi.com/documentation/computers/remote-access.html#vnc)。

## 3. 系统更新和依赖项

### 更新系统包
```bash
sudo apt update
sudo apt upgrade -y
```

### 安装基本包
```bash
sudo apt install -y python3-pip git curl wget
```

## 4. 启用SSH访问(可选)

### 启用SSH
```bash
sudo systemctl enable ssh
sudo systemctl start ssh
```

### 查找您的Pi的IP地址
```bash
hostname -I
```

### 从您的PC连接
```bash
ssh pi@<your-pi-ip-address>
```

## 5. 安装XLeRobot软件

按照官方[软件安装说明](https://huggingface.co/docs/lerobot/installation#install-lerobot-)获取详细步骤。

并复制[配置文件](https://xlerobot.readthedocs.io/en/latest/index.html)。

## 下一步

完成此设置后，您可以像笔记本电脑一样运行代码：



## 其他资源

- [官方树莓派文档](https://www.raspberrypi.org/documentation/)
- [RealVNC设置指南](https://pidoc.cn/docs/computers/getting-started)
- [XLeRobot GitHub仓库](https://xlerobot.readthedocs.io/en/latest/index.html)

## Lekiwi

```{note}
要使用Lekiwi代码测试XLeRobot的单臂版本，您应该拆下与底座不共享同一电机控制板的SO101手臂，将其夹在桌子上并连接到PC作为主导手臂。
```
```{note}
对于移动底座版本，您需要提前准备一个树莓派。
```

按照他们的所有[软件说明](https://huggingface.co/docs/lerobot/lekiwi)，这样您就可以：
-  [在树莓派上安装软件](https://huggingface.co/docs/lerobot/lekiwi#install-software-on-pi)并设置SSH 
-  [在PC上安装LeRobot](https://huggingface.co/docs/lerobot/installation)
-  [更新配置](https://github.com/huggingface/lerobot/blob/main/examples/11_use_lekiwi.md#update-config)
-  [校准](https://huggingface.co/docs/lerobot/il_robots#set-up-and-calibrate)

完成这些步骤后，您应该能够[像Lekiwi一样](https://github.com/huggingface/lerobot/blob/main/examples/11_use_lekiwi.md#f-teleoperate)遥操作XLeRobot的基础单臂版本，以复制此演示视频：

<video width="100%" style="max-width: 100%;" controls>
  <source src="https://github.com/user-attachments/assets/98312e30-9a5d-41a1-a6ce-ef163c3abfd5" type="video/mp4">
  Your browser does not support the video tag.
</video>

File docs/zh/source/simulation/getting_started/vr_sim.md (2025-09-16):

# XLeVR教程

本指南说明如何使用VR设备(目前支持Meta Quest3)在XLeRobot仿真环境中进行交互式控制。涵盖环境设置、依赖项、VR数据流、运行演示、故障排除和高级用法。

---

## 1. 环境设置

### 1.1 依赖项

确保您已安装以下内容：

- Python 3.7+
- [ManiSkill](https://github.com/haosulab/ManiSkill)
- [XLeVR](../../../XLeVR/README.md) (包含在此仓库中)

安装示例：

```bash
# 安装ManiSkill和依赖项
pip install mani-skill
# 安装XLeVR依赖项
cd XLeVR
pip install -r requirements.txt
```

---

## 2. VR集成和数据流

### 2.1 VR数据流概述

XLeVR使用WebSocket服务器从VR头显和控制器流式传输实时数据，并通过HTTPS提供网页UI进行监控。核心数据结构是`ControlGoal`，包括位置、方向、按钮状态等信息。

#### ControlGoal主要字段

- `arm`: 设备类型 ("left", "right", "headset")
- `target_position`: 3D坐标 (numpy数组)
- `wrist_roll_deg`/`wrist_flex_deg`: 手腕翻滚/俯仰角度
- `gripper_closed`: 夹爪是否闭合
- `metadata`: 额外信息 (扳机、摇杆等)

### 2.2 启动VR监控服务

从`XLeVR`目录运行：

```bash
python vr_monitor.py
```

- 终端将显示一个HTTPS地址 (例如, `https://<your-ip>:8443`)。在您的VR头显浏览器中打开此地址以查看实时控制数据。
- 您也可以将`vr_monitor.py`复制到另一个项目文件夹，并编辑脚本顶部的`XLEVR_PATH`变量。

---

## 3. 在仿真中使用VR控制

### 3.1 运行VR控制演示

对于ManiSkill环境，运行：

```bash
python -m mani_skill.examples.demo_ctrl_action_ee_VR \
 -e "ReplicaCAD_SceneManipulation-v1" \
 --render-mode="human" \
 --shader="rt-fast" \
 -c "pd_joint_delta_pos_dual_arm" \
 -r "xlerobot" \

```

- `-e` 设置环境 (例如, `ReplicaCAD_SceneManipulation-v1`, AI2THOR, Robocasa等)
- `--render-mode` 应该设为 `human` 以进行实时可视化
- `-c` 设置控制模式

### 3.2 控制说明

- **移动控制器**: 控制双臂的末端执行器位置
- **扳机**: 打开/关闭夹爪
- **摇杆**: 移动/旋转机器人底座
- **头显**: 用于视点/姿态数据
- **网页UI**: 显示实时设备状态和数据

---

## 5. 故障排除

### 5.1 启动错误

- 检查`XLEVR_PATH`是否设置正确
- 如果证书(`cert.pem`/`key.pem`)缺失，生成它们或禁用HTTPS

### 5.2 无VR数据

- 确保VR头显已连接并访问正确的HTTPS地址
- 检查防火墙/端口设置

### 5.3 控制问题

- 检查VR设备驱动程序和固件
- 确保`vr_monitor.py`正在运行

---

## 6. 高级用法

### 6.1 在代码中访问VR数据

您可以在Python中直接访问VR控制目标：

```python
from mani_skill.examples.vr_monitor import VRMonitor

monitor = VRMonitor()
monitor.initialize()
left_goal = monitor.get_left_goal_nowait()
right_goal = monitor.get_right_goal_nowait()
# left_goal/right_goal是ControlGoal对象
```

### 6.2 数据结构参考

详情请参见[XLeVR/README.md](../../../XLeVR/README.md)或`vr_monitor.py`代码。

---

## 7. 参考资料

- [ManiSkill文档](https://maniskill.readthedocs.io/en/latest/user_guide/datasets/scenes.html)
- [Oculus Reader文档](https://github.com/rail-berkeley/oculus_reader)
- [XLeVR/telegrip](https://github.com/DipFlip/telegrip)

---

如有其他问题，请提交issue或查看代码注释。

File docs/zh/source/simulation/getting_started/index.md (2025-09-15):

# 开始使用

### 前提条件

- Ubuntu操作系统
- 基本熟悉终端命令
- [Miniconda](https://docs.anaconda.com/free/miniconda/index.html) (推荐)

### 安装

#### 1. 创建Conda环境

如果您已经有一个`lerobot` conda环境，可以使用该环境。否则，创建一个新环境：

```bash
conda create -y -n lerobot python=3.11
conda activate lerobot

```

> 注意：建议将ManiSkill和lerobot代码放在同一个环境中，以便未来的sim2real部署。
> 

#### 2. 安装ManiSkill

按照ManiSkill的[官方安装说明](https://maniskill.readthedocs.io/en/latest/user_guide/getting_started/installation.html)进行安装。

```bash
# 基本安装
pip install mani-skill

# 下载场景数据集
python -m mani_skill.utils.download_asset "ReplicaCAD"

```

如果数据集下载出现问题，您可以直接从[这个Google Drive链接](https://drive.google.com/file/d/1mqImztNX1LYZFBzt9z895C814RsyGe4N/view?usp=sharing)下载数据集。然后文件夹内容应该放到

```bash
~/.maniskill/data/scene_datasets/replica_cad_dataset

```

使用[快速入门指南](https://maniskill.readthedocs.io/en/latest/user_guide/getting_started/quickstart.html)和[演示脚本](https://maniskill.readthedocs.io/en/latest/user_guide/getting_started/quickstart.html)熟悉ManiSkill。

尝试此命令来测试您是否成功安装了ManiSkill：

```{note}
将shader="rt-fast"更改为"default"以获得更快的渲染，或者如果您的计算机不支持光线追踪渲染。
```

```bash
python -m mani_skill.examples.demo_random_action -e "ReplicaCAD_SceneManipulation-v1" \
  --render-mode="human" --shader="rt-fast"

```

您应该看到类似这样的内容：



#### 3. 额外依赖

我们使用pygame来读取键盘输入并实时显示控制面板，使用Rerun来可视化和收集相机数据。

```bash
pip install pygame
pip install rerun-sdk
```

#### 4. 将XLeRobot文件放入ManiSkill

```{note}
我们期待ManiSkill很快为XLeRobot提供官方支持，之后可以跳过此步骤。
```

导航到您conda环境中的ManiSkill包文件夹：

```bash
cd ~/miniconda3/envs/lerobot/lib/python3.10/site-packages/mani_skill
```

将XLeRobot文件放入ManiSkill文件夹：

1. 在[这里下载**XLeRobot机器人文件**](https://github.com/Vector-Wangel/XLeRobot/tree/main/simulation/Maniskill)：
2. 将文件放入/agents/robots、/assets/robots和/envs/scenes：
   
   
   

   

   将XLeRobot机器人描述文件放入/agents/robots后，在/agents/robots/init.py中添加这一行
   
    
4. 将控制代码添加到/examples：
    
    

5. 修改utils/scene_builder/replicacad/scenebulider.py：对于新的机器人id，您需要先将它们添加到ReplicaCAD场景中。

   

#### 开始运行

```{note}
将shader="default"更改为"rt-fast"以获得照片级真实感光线追踪渲染(但更慢)。
```

##### 关节控制

```bash
python -m mani_skill.examples.demo_ctrl_action -e "ReplicaCAD_SceneManipulation-v1" -r "xlerobot"  --render-mode="human" --shader="default" -c "pd_joint_delta_pos_dual_arm"

```


##### 末端执行器控制 

原始双臂版本：

```bash
python -m mani_skill.examples.demo_ctrl_action_ee_keyboard -e "ReplicaCAD_SceneManipulation-v1" -r "xlerobot"  --render-mode="human" --shader="default" -c "pd_joint_delta_pos_dual_arm"

```

单臂版本：

```
python -m mani_skill.examples.demo_ctrl_action_ee_keyboard_single -e "ReplicaCAD_SceneManipulation-v1" -r "xlerobot_single"  --render-mode="human" --shader="default" -c "pd_joint_delta_pos"
```

通过Rerun进行相机可视化：

```bash
python -m mani_skill.examples.demo_ctrl_action_ee_cam_rerun -e "ReplicaCAD_SceneManipulation-v1" -r "xlerobot"  --render-mode="human" --shader="default" -c "pd_joint_delta_pos_dual_arm"

```



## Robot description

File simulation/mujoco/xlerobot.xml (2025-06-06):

<mujoco model="xlerobot">
  <compiler angle="radian" meshdir="./assets/"/>

  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

  <default>
    <default class="so_arm100">
      <joint frictionloss="0.1" armature="0.1"/>
      <position kp="50" dampratio="1" forcerange="-35 35" ctrlrange="-3.14158 3.14158"/>
      <default class="Rotation">
        <joint axis="0 1 0" range="-2.2 2.2"/>
      </default>
      <default class="Pitch">
        <joint axis="1 0 0" range="-3.14158 0.2"/>
      </default>
      <default class="Elbow">
        <joint axis="1 0 0" range="0 3.14158"/>
      </default>
      <default class="Wrist_Pitch">
        <joint axis="1 0 0" range="-2.0 1.8"/>
      </default>
      <default class="Wrist_Roll">
        <joint axis="0 1 0" range="-3.14158 3.14158"/>
      </default>
      <default class="Jaw">
        <joint axis="0 0 1" range="-0.2 2.0"/>
      </default>
      <default class="visual">
        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
        <default class="motor_visual">
          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
        </default>
      </default>
      <default class="collision">
        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
        <default class="finger_collision">
          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
        </default>
      </default>
    </default>
  </default>

  <tendon>
    <fixed name="slider_actuator_x">
      <joint joint="ST3215_Servo_Motor-v1-2_Hub---Servo" coef="0"/>
      <joint joint="ST3215_Servo_Motor-v1-1_Hub-2---Servo" coef="-0.5"/>
      <joint joint="ST3215_Servo_Motor-v1_Revolute-40" coef="0.5"/>
    </fixed>
    
    <fixed name="slide">
      <joint joint="ST3215_Servo_Motor-v1-2_Hub---Servo" coef="0.0"/>
      <joint joint="ST3215_Servo_Motor-v1-1_Hub-2---Servo" coef="0.286"/>
      <joint joint="ST3215_Servo_Motor-v1_Revolute-40" coef="-0.286"/>
    </fixed>
    
    <fixed name="rotate">
      <joint joint="ST3215_Servo_Motor-v1-2_Hub---Servo" coef="0.33"/>
      <joint joint="ST3215_Servo_Motor-v1-1_Hub-2---Servo" coef="0.33"/>
      <joint joint="ST3215_Servo_Motor-v1_Revolute-40" coef="0.33"/>
    </fixed>
  </tendon>

  <worldbody>
    <light directional="true" pos="-0.5 0.5 3" dir="0 0 -1" />
    <body name="chassis" pos="0 0 0.035" quat="0.707108 0 0 0.707108">
      <joint name="slide_joint_x" type="slide" axis="1 0 0" damping="0.1"/>
      <joint name="slide_joint_y" type="slide" axis="0 1 0" damping="0.1"/>
      <joint name="hinge_joint_z" type="hinge" axis="0 0 1" damping="0.1"/>
      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

      <body name="base_plate_layer1-v5-1" pos="0.0 0.0 0.0" euler="0.0 0.0 -1.5708">
        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
        <inertial mass="1.9468624348344596" pos="-4.730687660675253e-15 -2.7155537377808555e-05 -0.0035000000000000005" fullinertia="0.005637109888809055 0.005628440956780792 0.0112496514690387 1.3447333053523504e-16 1.7848833522297417e-20 2.6469779601696886e-23" />
        <body name="drive_motor_mount-v4-3" pos="-0.020610000007450578 -0.09 0.0020000000000000018" euler="-0.0 0.0 -1.5707963267948966">
          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
          <inertial mass="0.035884017191401885" pos="0.00017900181977195112 -0.0006914486154622601 0.0004348187449640745" fullinertia="3.2235542654871883e-06 3.901284246443171e-06 6.890721819180175e-06 -1.4488185386067676e-08 -3.4701845947883736e-08 1.0877684749210782e-07" />
          <body name="ST3215_Servo_Motor-v1-2" pos="0.00959999999999999 -0.004889999992549421 0.01436" euler="-6.123233995736766e-17 0.0 -1.5707963267948968">
            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
            <inertial mass="0.0658962961901927" pos="-0.014664257020729004 -0.008722816656342332 1.2191853053420506e-06" fullinertia="1.0300908387946657e-05 1.3913691655689984e-05 1.8215748982019662e-05 1.1951581712694353e-07 -1.7998869276644268e-09 8.88550145137008e-10" />
            <body name="3_8-Hex-Bore-Plastic-VersaHub-217-5828-v2-2" pos="-0.025500000000000002 0.011187500000000003 2.220446049250313e-18" euler="-1.5707963267948966 1.5192908393215678e-64 3.141592653589793">
              <joint name="ST3215_Servo_Motor-v1-2_Hub---Servo" type="hinge" axis="6.887535064975403e-49 -3.749399456654644e-33 1.0" pos="-4.4408920985006255e-18 -3.469446951953615e-18 -0.0015874999999999917"/>
              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
              <inertial mass="0.08665496109754897" pos="8.50877658112488e-09 7.358945011137765e-09 0.0023811166424899887" fullinertia="1.2296291761641504e-05 1.2296276073121143e-05 2.2911778015411222e-05 -3.19167294920219e-12 1.755992026942528e-12 1.5186622033709633e-12" />
              <body name="4-Omni-Directional-Wheel_Single_Body-v1-2" pos="-2.453269466693399e-18 0.0 0.0174625" euler="-3.141592653589793 -1.5192908393215678e-64 -0.2617993877991494">
                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
                <inertial mass="1.3542854082324305" pos="-7.105207895657716e-08 -1.1369917947312704e-07 -1.2090586078983279e-08" fullinertia="0.0010936200374455458 0.0010936108480286116 0.0018798127501507855 -5.245142023675448e-09 4.046730352778215e-10 1.0004485488405523e-10" />
              </body>
            </body>
          </body>
        </body>
        <body name="drive_motor_mount-v4-2" pos="0.08824728634432479 0.027151216421550314 0.001999999999999993" euler="-0.0 0.0 0.5235987755982997">
          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
          <inertial mass="0.035884017191401885" pos="0.00017900181977194513 -0.0006914486154622601 0.00043481874496407525" fullinertia="3.2235542654872044e-06 3.901284246443212e-06 6.890721819180191e-06 -1.4488185386052894e-08 -3.470184594788067e-08 1.0877684749210813e-07" />
          <body name="ST3215_Servo_Motor-v1-1" pos="0.010400000000000081 -0.004889999992549394 0.014359999999999984" euler="-6.406864442435952e-17 -7.857775794700331e-16 -1.570796326794897">
            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
            <inertial mass="0.0658962961901927" pos="-0.014664257020728995 -0.008722816656342374 1.2191853053600496e-06" fullinertia="1.0300908387946253e-05 1.391369165569022e-05 1.8215748982019256e-05 1.1951581712706042e-07 -1.7998869276893484e-09 8.885501451146896e-10" />
            <body name="3_8-Hex-Bore-Plastic-VersaHub-217-5828-v2-1" pos="-0.02550000000000004 0.011187499999999986 0.0" euler="-1.5707963267948966 2.220446049250324e-16 1.6021677874353734e-16">
              <joint name="ST3215_Servo_Motor-v1-1_Hub-2---Servo" type="hinge" axis="-2.018922194424455e-07 5.551115123125783e-17 0.9999996503124187" pos="1.0279185592260934e-07 6.850769951327593e-18 -0.0015873219592831226" />
              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
              <inertial mass="0.08665496109754897" pos="8.508776579152501e-09 7.358945011269938e-09 0.0023811166424899787" fullinertia="1.2296291761641589e-05 1.2296276073121566e-05 2.2911778015411107e-05 -3.1916729680995547e-12 1.755991986238418e-12 1.5186621750295066e-12" />
              <body name="4-Omni-Directional-Wheel_Single_Body-v1-1" pos="-8.88178419700111e-18 3.3306690738754695e-17 0.01746250000000007" euler="3.141592653589793 5.5511151231257747e-17 1.8325957145940461">
                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
                <inertial mass="1.3542854082324305" pos="-7.105207896524954e-08 -1.1369917948959942e-07 -1.2090586104095832e-08" fullinertia="0.0010936200374455313 0.0010936108480285981 0.0018798127501507892 -5.2451420243259696e-09 4.0467303541420525e-10 1.0004485627777097e-10" />
              </body>
            </body>
          </body>
        </body>
        <body name="drive_motor_mount-v4-1" pos="-0.06763728633687423 0.06284878357844971 0.0020000000000000018" euler="5.415442118703716e-17 -1.3598996028091536e-16 2.617993877991494">
          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
          <inertial mass="0.035884017191401885" pos="0.0001790018197719455 -0.0006914486154622614 0.0004348187449640748" fullinertia="3.2235542654871925e-06 3.901284246443185e-06 6.890721819180079e-06 -1.4488185386019653e-08 -3.470184594788136e-08 1.087768474921115e-07" />
          <body name="ST3215_Servo_Motor-v1" pos="0.00959999999999999 -0.004889999992549434 0.014360000000000013" euler="2.2863854877850107e-16 -1.2117128698533114e-16 -1.5707963267948966">
            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

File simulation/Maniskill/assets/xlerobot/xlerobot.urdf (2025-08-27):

<?xml version="1.0" encoding="utf-8"?>

<robot name="xlerobot">

  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

  <link name="root">
    <inertial>
      <mass value="0"/>
      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
    </inertial>
  </link>

  <link name="root_arm_1_link_1">
    <inertial>
      <mass value="0"/>
      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
    </inertial>
  </link>

  <link name="root_arm_1_link_2">
    <inertial>
      <mass value="0"/>
      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
    </inertial>
  </link>

  <joint name="root_x_axis_joint" type="prismatic">
    <parent link="root"/>
    <child link="root_arm_1_link_1"/>
    <axis xyz="1 0 0"/>
    <limit effort="100" lower="-20" upper="20" velocity="0.50"/>
    <dynamics damping="10.0" friction="10"/>
  </joint>

  <joint name="root_y_axis_joint" type="prismatic">
    <parent link="root_arm_1_link_1"/>
    <child link="root_arm_1_link_2"/>
    <axis xyz="0 1 0"/>
    <limit effort="100" lower="-20" upper="20" velocity="0.50"/>
    <dynamics damping="10.0" friction="10"/>
  </joint>

  <joint name="root_z_rotation_joint" type="continuous">
    <parent link="root_arm_1_link_2"/>
    <child link="base_link"/>
    <axis xyz="0 0 1"/>
    <dynamics damping="10.0" friction="1"/>
  </joint>

  <link name="base_link">
    <inertial>
      <origin rpy="0 0 0" xyz="0 0.0 0.38"/>
      <mass value="70.1294"/>
      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
    </inertial>


    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
  </link>




  <link name="Base">
    <inertial>
      <origin xyz="-2.45960666746703E-07 0.0311418169687909 0.0175746661003382" rpy="0 0 0" />
      <mass value="0.193184127927598" />
      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
    </inertial>
    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
  </link>

  <joint name="arm_base_joint" type="fixed">
    <origin rpy="0 0 1.5708" xyz="-0.135 -0.133 0.760"/>
    <parent link="base_link"/>
    <child link="Base"/>
    <axis xyz="0 1 0"/>
    <limit effort="8.85" velocity="17.4"/>
  </joint>

  <link name="Rotation_Pitch">
    <inertial>
      <origin xyz="-9.07886224712597E-05 0.0590971820568318 0.031089016892169" rpy="0 0 0" />
      <mass value="0.119226314127197" />
      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
    </inertial>
    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
  </link>
  <joint name="Rotation" type="revolute">
    <origin xyz="0 -0.0452 0.0165" rpy="1.5708 0 0" />
    <parent link="Base" />
    <child link="Rotation_Pitch" />
    <axis xyz="0 -1 0" />
      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
    <limit lower="-2.1" upper="2.1" effort="0" velocity="0" />
  </joint>
  <link name="Upper_Arm">
    <inertial>
      <origin xyz="-1.7205170190925E-05 0.0701802156327694 0.00310545118155671" rpy="0 0 0" />
      <mass value="0.162409284599177" />
      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
    </inertial>
    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
  </link>
  <joint name="Pitch" type="revolute">
    <origin xyz="0 0.1025 0.0306" rpy="1.5708 0 0" />
    <parent link="Rotation_Pitch" />
    <child link="Upper_Arm" />
    <axis xyz="-1 0 0" />
    <limit lower="-0.1" upper="3.45" effort="0" velocity="0" />
  </joint>
  <link name="Lower_Arm">
    <inertial>
      <origin xyz="-0.00339603710186651 0.00137796353960074 0.0768006751156044" rpy="0 0 0" />
      <mass value="0.147967774582291" />
      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
    </inertial>
    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
  </link>
  <joint name="Elbow" type="revolute">
    <origin xyz="0 0.11257 0.028" rpy="-1.5708 0 0" />
    <parent link="Upper_Arm" />
    <child link="Lower_Arm" />
    <axis xyz="1 0 0" />
    <limit lower="-0.2" upper="3.14159" effort="0" velocity="0" />
  </joint>
  <link name="Wrist_Pitch_Roll">
    <inertial>
      <origin xyz="-0.00852653127372418 -0.0352278997897927 -2.34622481569413E-05" rpy="0 0 0" />
      <mass value="0.066132067097723" />
      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
    </inertial>
    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
  </link>
  <joint name="Wrist_Pitch" type="revolute">
    <origin xyz="0 0.0052 0.1349" rpy="-1.5708 0 0" />
    <parent link="Lower_Arm" />
    <child link="Wrist_Pitch_Roll" />
    <axis xyz="1 0 0" />
    <limit lower="-1.8" upper="1.8" effort="0" velocity="0" />
  </joint>
  <link name="Fixed_Jaw">
    <inertial>
      <origin xyz="0.00552376906426563 -0.0280167153359021 0.000483582592841092" rpy="0 0 0" />
      <mass value="0.0929859131176897" />
      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
    </inertial>
    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
  </link>
  <joint name="Wrist_Roll" type="revolute">
    <origin xyz="0 -0.0601 0" rpy="0 1.5708 0" />
    <parent link="Wrist_Pitch_Roll" />
    <child link="Fixed_Jaw" />
    <axis xyz="0 -1 0" />
    <limit lower="-3.14159" upper="3.14159" effort="0" velocity="0" />
  </joint>
  <link name="Moving_Jaw">
    <inertial>
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

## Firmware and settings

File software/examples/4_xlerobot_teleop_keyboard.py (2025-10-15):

# To Run on the host
'''python
PYTHONPATH=src python -m lerobot.robots.xlerobot.xlerobot_host --robot.id=my_xlerobot
'''

# To Run the teleop:
'''python
PYTHONPATH=src python -m examples.xlerobot.teleoperate_Keyboard
'''

import time
import numpy as np
import math

from lerobot.robots.xlerobot import XLerobotConfig, XLerobot
# from lerobot.robots.xlerobot import XLerobotClient, XLerobotClientConfig
from lerobot.utils.robot_utils import busy_wait
from lerobot.utils.visualization_utils import init_rerun, log_rerun_data
from lerobot.model.SO101Robot import SO101Kinematics
from lerobot.teleoperators.keyboard.teleop_keyboard import KeyboardTeleop, KeyboardTeleopConfig

# Keymaps (semantic action: key)
LEFT_KEYMAP = {
    'shoulder_pan+': 'q', 'shoulder_pan-': 'e',
    'wrist_roll+': 'r', 'wrist_roll-': 'f',
    'gripper+': 't', 'gripper-': 'g',
    'x+': 'w', 'x-': 's', 'y+': 'a', 'y-': 'd',
    'pitch+': 'z', 'pitch-': 'x',
    'reset': 'c',
    # For head motors
    "head_motor_1+": "<", "head_motor_1-": ">",
    "head_motor_2+": ",", "head_motor_2-": ".",
    
    'triangle': 'y',  # Rectangle trajectory key
}
RIGHT_KEYMAP = {
    'shoulder_pan+': '7', 'shoulder_pan-': '9',
    'wrist_roll+': '/', 'wrist_roll-': '*',
    'gripper+': '+', 'gripper-': '-',
    'x+': '8', 'x-': '2', 'y+': '4', 'y-': '6',
    'pitch+': '1', 'pitch-': '3',
    'reset': '0',

    'triangle': 'Y',  # Rectangle trajectory key
}

LEFT_JOINT_MAP = {
    "shoulder_pan": "left_arm_shoulder_pan",
    "shoulder_lift": "left_arm_shoulder_lift",
    "elbow_flex": "left_arm_elbow_flex",
    "wrist_flex": "left_arm_wrist_flex",
    "wrist_roll": "left_arm_wrist_roll",
    "gripper": "left_arm_gripper",
}
RIGHT_JOINT_MAP = {
    "shoulder_pan": "right_arm_shoulder_pan",
    "shoulder_lift": "right_arm_shoulder_lift",
    "elbow_flex": "right_arm_elbow_flex",
    "wrist_flex": "right_arm_wrist_flex",
    "wrist_roll": "right_arm_wrist_roll",
    "gripper": "right_arm_gripper",
}

# Head motor mapping
HEAD_MOTOR_MAP = {
    "head_motor_1": "head_motor_1",
    "head_motor_2": "head_motor_2",
}

class RectangularTrajectory:
    """
    Generates a rectangular trajectory on the x-y plane with sinusoidal velocity profiles.
    The rectangle is divided into 4 line segments, each with smooth acceleration/deceleration.
    """
    def __init__(self, width=0.06, height=0.06, segment_duration=0.91):
        """
        Initialize rectangular trajectory parameters.
        
        Args:
            width: Rectangle width in meters
            height: Rectangle height in meters  
            segment_duration: Time for each line segment in seconds
        """
        self.width = width
        self.height = height
        self.segment_duration = segment_duration
        self.total_duration = 4 * segment_duration
        
    def get_trajectory_point(self, current_x, current_y, t):
        """
        Get the target x, y position at time t for the rectangular trajectory.
        
        Args:
            current_x: Starting x position
            current_y: Starting y position
            t: Time since trajectory start (0 to total_duration)
            
        Returns:
            tuple: (target_x, target_y)
        """
        # Determine which segment we're in
        segment = int(t / self.segment_duration)
        segment_t = t % self.segment_duration
        
        # Normalize segment time (0 to 1)
        normalized_t = segment_t / self.segment_duration
        
        # Sinusoidal velocity profile: smooth acceleration and deceleration
        # s(t) = 0.5 * (1 - cos(π * t)) gives smooth 0 to 1 transition
        smooth_t = 0.5 * (1 - math.cos(math.pi * normalized_t))
        
        # Define rectangle corners relative to starting position
        corners = [
            (current_x, current_y),                           # Start (bottom-left)
            (current_x + self.width, current_y),              # Bottom-right
            (current_x + self.width, current_y + self.height), # Top-right  
            (current_x, current_y + self.height),             # Top-left
            (current_x, current_y)                            # Back to start
        ]
        
        # Clamp segment to valid range
        segment = max(0, min(3, segment))
        
        # Interpolate between current corner and next corner
        start_corner = corners[segment]
        end_corner = corners[segment + 1]
        
        target_x = start_corner[0] + smooth_t * (end_corner[0] - start_corner[0])
        target_y = start_corner[1] + smooth_t * (end_corner[1] - start_corner[1])
        
        return target_x, target_y

class SimpleHeadControl:
    def __init__(self, initial_obs, kp=0.81):
        self.kp = kp
        self.degree_step = 1
        # Initialize head motor positions
        self.target_positions = {
            "head_motor_1": initial_obs.get("head_motor_1.pos", 0.0),
            "head_motor_2": initial_obs.get("head_motor_2.pos", 0.0),
        }
        self.zero_pos = {"head_motor_1": 0.0, "head_motor_2": 0.0}

    def move_to_zero_position(self, robot):
        self.target_positions = self.zero_pos.copy()
        action = self.p_control_action(robot)
        robot.send_action(action)

    def handle_keys(self, key_state):
        if key_state.get('head_motor_1+'):
            self.target_positions["head_motor_1"] += self.degree_step
            print(f"[HEAD] head_motor_1: {self.target_positions['head_motor_1']}")
        if key_state.get('head_motor_1-'):
            self.target_positions["head_motor_1"] -= self.degree_step
            print(f"[HEAD] head_motor_1: {self.target_positions['head_motor_1']}")
        if key_state.get('head_motor_2+'):
            self.target_positions["head_motor_2"] += self.degree_step
            print(f"[HEAD] head_motor_2: {self.target_positions['head_motor_2']}")
        if key_state.get('head_motor_2-'):
            self.target_positions["head_motor_2"] -= self.degree_step
            print(f"[HEAD] head_motor_2: {self.target_positions['head_motor_2']}")

    def p_control_action(self, robot):
        obs = robot.get_observation()
        action = {}
        for motor in self.target_positions:
            current = obs.get(f"{HEAD_MOTOR_MAP[motor]}.pos", 0.0)
            error = self.target_positions[motor] - current
            control = self.kp * error
            action[f"{HEAD_MOTOR_MAP[motor]}.pos"] = current + control
        return action

class SimpleTeleopArm:
    def __init__(self, kinematics, joint_map, initial_obs, prefix="left", kp=0.81):
        self.kinematics = kinematics
        self.joint_map = joint_map
        self.prefix = prefix  # To distinguish left and right arm
        self.kp = kp
        # Initial joint positions
        self.joint_positions = {
            "shoulder_pan": initial_obs[f"{prefix}_arm_shoulder_pan.pos"],
            "shoulder_lift": initial_obs[f"{prefix}_arm_shoulder_lift.pos"],
            "elbow_flex": initial_obs[f"{prefix}_arm_elbow_flex.pos"],
            "wrist_flex": initial_obs[f"{prefix}_arm_wrist_flex.pos"],
            "wrist_roll": initial_obs[f"{prefix}_arm_wrist_roll.pos"],
            "gripper": initial_obs[f"{prefix}_arm_gripper.pos"],
        }
        # Set initial x/y to fixed values
        self.current_x = 0.1629
        self.current_y = 0.1131
        self.pitch = 0.0
        # Set the degree step and xy step
        self.degree_step = 3
        self.xy_step = 0.0081
        # Set target positions to zero for P control
        self.target_positions = {
            "shoulder_pan": 0.0,
            "shoulder_lift": 0.0,
            "elbow_flex": 0.0,
            "wrist_flex": 0.0,
            "wrist_roll": 0.0,
            "gripper": 0.0,
        }
        self.zero_pos = {
            'shoulder_pan': 0.0,
            'shoulder_lift': 0.0,
            'elbow_flex': 0.0,
            'wrist_flex': 0.0,
            'wrist_roll': 0.0,
            'gripper': 0.0
        }
        
        # Rectangular trajectory instance
        self.rectangular_trajectory = RectangularTrajectory(
            width=0.06,          # 6cm wide rectangle
            height=0.06,         # 4cm tall rectangle  
            segment_duration=1.01 # 3 seconds per line segment
        )

    def move_to_zero_position(self, robot):
        print(f"[{self.prefix}] Moving to Zero Position: {self.zero_pos} ......")
        self.target_positions = self.zero_pos.copy()  # Use copy to avoid reference issues
        
        # Reset kinematic variables to their initial state
        self.current_x = 0.1629
        self.current_y = 0.1131
        self.pitch = 0.0
        
        # Don't let handle_keys recalculate wrist_flex - set it explicitly
        self.target_positions["wrist_flex"] = 0.0
        
        action = self.p_control_action(robot)
        robot.send_action(action)

    def execute_rectangular_trajectory(self, robot, fps=30):
        """
        Execute a blocking rectangular trajectory on the x-y plane.
        
        Args:
            robot: Robot instance to send actions to
            fps: Control loop frequency
        """
        print(f"[{self.prefix}] Starting rectangular trajectory...")
        print(f"[{self.prefix}] Rectangle: {self.rectangular_trajectory.width:.3f}m x {self.rectangular_trajectory.height:.3f}m")
        print(f"[{self.prefix}] Duration: {self.rectangular_trajectory.total_duration:.3f}s total")
        
        # Store starting position
        start_x = self.current_x
        start_y = self.current_y
        
        # Execute trajectory
        start_time = time.time()
        dt = 1.0 / fps
        
        while True:
            current_time = time.time()
            elapsed_time = current_time - start_time
            
            # Check if trajectory is complete
            if elapsed_time >= self.rectangular_trajectory.total_duration:
                print(f"[{self.prefix}] Rectangular trajectory completed!")
                break
                
            # Get target position from trajectory
            target_x, target_y = self.rectangular_trajectory.get_trajectory_point(
                start_x, start_y, elapsed_time
            )
            
            # Update current position
            self.current_x = target_x
            self.current_y = target_y
            
            # Calculate inverse kinematics
            try:
                joint2, joint3 = self.kinematics.inverse_kinematics(self.current_x, self.current_y)
                self.target_positions["shoulder_lift"] = joint2
                self.target_positions["elbow_flex"] = joint3
                
                # Update wrist_flex coupling
                self.target_positions["wrist_flex"] = (
                    -self.target_positions["shoulder_lift"]
                    -self.target_positions["elbow_flex"]
                    + self.pitch
                )
                
                # Get action
                action = self.p_control_action(robot)
                
                # Determine which arm is executing and send appropriate action structure
                if self.prefix == "left":
                    # Send left arm action with empty actions for other components
                    robot_action = {**action, **{}, **{}, **{}}
                elif self.prefix == "right":
                    # Send right arm action with empty actions for other components
                    robot_action = {**{}, **action, **{}, **{}}
                
                # Send action to robot
                robot.send_action(robot_action)
                
                # Get observation and log data
                obs = robot.get_observation()
                log_rerun_data(obs, robot_action)
                
            except Exception as e:
                print(f"[{self.prefix}] IK failed at x={self.current_x:.4f}, y={self.current_y:.4f}: {e}")
                break
                
            # Maintain control frequency
            # busy_wait(dt)
        
        print(f"[{self.prefix}] Trajectory execution finished.")

    def handle_keys(self, key_state):
        # Joint increments
        if key_state.get('shoulder_pan+'):
            self.target_positions["shoulder_pan"] += self.degree_step
            print(f"[{self.prefix}] shoulder_pan: {self.target_positions['shoulder_pan']}")
        if key_state.get('shoulder_pan-'):
            self.target_positions["shoulder_pan"] -= self.degree_step
            print(f"[{self.prefix}] shoulder_pan: {self.target_positions['shoulder_pan']}")
        if key_state.get('wrist_roll+'):
            self.target_positions["wrist_roll"] += self.degree_step
            print(f"[{self.prefix}] wrist_roll: {self.target_positions['wrist_roll']}")
        if key_state.get('wrist_roll-'):
            self.target_positions["wrist_roll"] -= self.degree_step
            print(f"[{self.prefix}] wrist_roll: {self.target_positions['wrist_roll']}")
        if key_state.get('gripper+'):
            self.target_positions["gripper"] += self.degree_step
            print(f"[{self.prefix}] gripper: {self.target_positions['gripper']}")
        if key_state.get('gripper-'):
            self.target_positions["gripper"] -= self.degree_step
            print(f"[{self.prefix}] gripper: {self.target_positions['gripper']}")
        if key_state.get('pitch+'):
            self.pitch += self.degree_step
            print(f"[{self.prefix}] pitch: {self.pitch}")
        if key_state.get('pitch-'):
            self.pitch -= self.degree_step
            print(f"[{self.prefix}] pitch: {self.pitch}")

        # XY plane (IK)
        moved = False
        if key_state.get('x+'):
            self.current_x += self.xy_step
            moved = True
            print(f"[{self.prefix}] x+: {self.current_x:.4f}, y: {self.current_y:.4f}")
        if key_state.get('x-'):
            self.current_x -= self.xy_step
            moved = True
            print(f"[{self.prefix}] x-: {self.current_x:.4f}, y: {self.current_y:.4f}")
        if key_state.get('y+'):
            self.current_y += self.xy_step
            moved = True
            print(f"[{self.prefix}] x: {self.current_x:.4f}, y+: {self.current_y:.4f}")
        if key_state.get('y-'):
            self.current_y -= self.xy_step
            moved = True
            print(f"[{self.prefix}] x: {self.current_x:.4f}, y-: {self.current_y:.4f}")
        if moved:
            joint2, joint3 = self.kinematics.inverse_kinematics(self.current_x, self.current_y)
            self.target_positions["shoulder_lift"] = joint2
            self.target_positions["elbow_flex"] = joint3
            print(f"[{self.prefix}] shoulder_lift: {joint2}, elbow_flex: {joint3}")

        # Wrist flex is always coupled to pitch and the other two
        self.target_positions["wrist_flex"] = (
            -self.target_positions["shoulder_lift"]
            -self.target_positions["elbow_flex"]
            + self.pitch
        )
        # print(f"[{self.prefix}] wrist_flex: {self.target_positions['wrist_flex']}")

    def p_control_action(self, robot):
        obs = robot.get_observation()
        current = {j: obs[f"{self.prefix}_arm_{j}.pos"] for j in self.joint_map}
        action = {}
        for j in self.target_positions:
            error = self.target_positions[j] - current[j]
            control = self.kp * error
            action[f"{self.joint_map[j]}.pos"] = current[j] + control
        return action
    

def main():
    # Teleop parameters
    FPS = 50
    # ip = "192.168.1.123"  # This is for zmq connection
    ip = "localhost"  # This is for local/wired connection
    robot_name = "my_xlerobot_pc"

    # For zmq connection
    # robot_config = XLerobotClientConfig(remote_ip=ip, id=robot_name)
    # robot = XLerobotClient(robot_config)    

    # For local/wired connection
    robot_config = XLerobotConfig()
    robot = XLerobot(robot_config)
    
    try:
        robot.connect()
        print(f"[MAIN] Successfully connected to robot")
    except Exception as e:
        print(f"[MAIN] Failed to connect to robot: {e}")
        print(robot_config)
        print(robot)
        return
        
    _init_rerun(session_name="xlerobot_teleop_v2")

    #Init the keyboard instance
    keyboard_config = KeyboardTeleopConfig()
    keyboard = KeyboardTeleop(keyboard_config)
    keyboard.connect()

    # Init the arm and head instances
    obs = robot.get_observation()
    kin_left = SO101Kinematics()
    kin_right = SO101Kinematics()
    left_arm = SimpleTeleopArm(kin_left, LEFT_JOINT_MAP, obs, prefix="left")
    right_arm = SimpleTeleopArm(kin_right, RIGHT_JOINT_MAP, obs, prefix="right")
    head_control = SimpleHeadControl(obs)

    # Move both arms and head to zero position at start
    left_arm.move_to_zero_position(robot)
    right_arm.move_to_zero_position(robot)

    try:
        while True:
            pressed_keys = set(keyboard.get_action().keys())
            left_key_state = {action: (key in pressed_keys) for action, key in LEFT_KEYMAP.items()}
            right_key_state = {action: (key in pressed_keys) for action, key in RIGHT_KEYMAP.items()}

            # Handle rectangular trajectory for left arm (y key)
            if left_key_state.get('triangle'):
                print("[MAIN] Left arm rectangular trajectory triggered!")
                left_arm.execute_rectangular_trajectory(robot, fps=FPS)
                continue

            # Handle rectangular trajectory for right arm (Y key)  
            if right_key_state.get('triangle'):
                print("[MAIN] Right arm rectangular trajectory triggered!")
                right_arm.execute_rectangular_trajectory(robot, fps=FPS)
                continue

            # Handle reset for left arm
            if left_key_state.get('reset'):
                left_arm.move_to_zero_position(robot)
                continue  

            # Handle reset for right arm
            if right_key_state.get('reset'):
                right_arm.move_to_zero_position(robot)
                continue

            # Handle reset for head motors with '?'
            if '?' in pressed_keys:
                head_control.move_to_zero_position(robot)
                continue

            left_arm.handle_keys(left_key_state)
            right_arm.handle_keys(right_key_state)
            head_control.handle_keys(left_key_state)  # Head controlled by left arm keymap

            left_action = left_arm.p_control_action(robot)
            right_action = right_arm.p_control_action(robot)
            head_action = head_control.p_control_action(robot)

            # Base action
            keyboard_keys = np.array(list(pressed_keys))
            base_action = robot._from_keyboard_to_base_action(keyboard_keys) or {}

            action = {**left_action, **right_action, **head_action, **base_action}
            robot.send_action(action)

            obs = robot.get_observation()
            # print(f"[MAIN] Observation: {obs}")
            log_rerun_data(obs, action)
            # busy_wait(1.0 / FPS)
    finally:
        robot.disconnect()
        keyboard.disconnect()
        print("Teleoperation ended.")

if __name__ == "__main__":
    main()

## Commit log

2025-04-27 Add files via upload
    3D print stls
    [Camera_Holder_Alternate_MF.stl, Print_Follower_SO_ARM100_08k_UP_BambuLabA1Mini_part1.STL, Print_Follower_SO_ARM100_08k_UP_BambuLabA1Mini_part2.STL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]
2025-06-06 feat: Add xlerobot_mujoco.py, mujoco mjcf with keyboard controller
    [3_8-Hex-Bore-Plastic-VersaHub-217-5828-v2-1.stl, 3_8-Hex-Bore-Plastic-VersaHub-217-5828-v2-2.stl, 3_8-Hex-Bore-Plastic-VersaHub-217-5828-v2.stl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]
2025-06-15 website draft
    [isaac_lab.csv, maniskill.csv]
2025-06-21 Update BOM_CN.md
    舵机的线应该是反向的，如果买了无法连接，可以和舵机的比较一下。
2025-06-23 draft 1
    [isaac_lab.csv, maniskill.csv]
2025-07-14 rearrange mujoco
    [3_8-Hex-Bore-Plastic-VersaHub-217-5828-v2-1.stl, 3_8-Hex-Bore-Plastic-VersaHub-217-5828-v2-2.stl, 3_8-Hex-Bore-Plastic-VersaHub-217-5828-v2.stl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]
2025-08-07 adding notes on cost of 3d printing
2025-08-12 Update 3d files
    [XLeRobot_Head_Connector_for_both_realsense_and_webcam.stl]
2025-08-27 add single arm urdf
    [fetch_single.urdf]
2025-08-27 formal robot file for xlerobot, with single arm version
    [Base.stl, Base.stl.convex.stl, Base_Motor.stl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]
2025-09-06 Simplify simulation assets
    [XLeRobot_camera1.stl, XLeRobot_camera2.stl, raskogwheel1.stl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]
2025-09-14 adds IN BOM details
2025-09-14 incorrect links to 6v instead of 12 servo
2025-09-20 Removed unnecessary parts from the file Neck.step
    [Neck.step]
2025-09-20 Added all step files for the RGBD gimbal
    [Gimbal_Base.step, Gimbal_Neck.step, Gimbal_Pitch_Holder_d435.step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]
2025-09-20 Added the upgraded drive motor mount
    [Drive_Motor_Mount_upgraded.step]
2025-09-20 Old Nimbal is archived
    [Headmount.step, Neck.step]
2025-09-20 Add stl mesh for d435 and d455 gimbals.
    [Gimbal_mesh_all_d435.stl, Gimbal_mesh_all_d455.stl]
2025-09-22 Refactored the strucuture of web control app.
    [3_8-Hex-Bore-Plastic-VersaHub-217-5828-v2-1.stl, 3_8-Hex-Bore-Plastic-VersaHub-217-5828-v2-2.stl, 3_8-Hex-Bore-Plastic-VersaHub-217-5828-v2.stl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]
2025-09-23 Refactored web_control
    [3_8-Hex-Bore-Plastic-VersaHub-217-5828-v2-1.stl, 3_8-Hex-Bore-Plastic-VersaHub-217-5828-v2-2.stl, 3_8-Hex-Bore-Plastic-VersaHub-217-5828-v2.stl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]
2025-09-23 Refactor web_contrl.
    [3_8-Hex-Bore-Plastic-VersaHub-217-5828-v2-1.stl, 3_8-Hex-Bore-Plastic-VersaHub-217-5828-v2-2.stl, 3_8-Hex-Bore-Plastic-VersaHub-217-5828-v2.stl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]
2025-09-23 Refactor web_control.
    [3_8-Hex-Bore-Plastic-VersaHub-217-5828-v2-1.stl, 3_8-Hex-Bore-Plastic-VersaHub-217-5828-v2-2.stl, 3_8-Hex-Bore-Plastic-VersaHub-217-5828-v2.stl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]
2025-09-23 update srdf for single arm
2025-09-26 xlerobot manskill simplification
    [xlerobot.urdf, xlerobot_front.urdf]
2025-10-03 Differential drive design
    [XLeRobot 035 wheels.stl]
2025-10-06 Fix top_base_joint
    [xlerobot.urdf]
2025-10-09 Ongoing hardware design
    [XLeRobot 035 armbase.stl, XLeRobot 035 wheels.step, XLeRobot 035 wheels.stl]
2025-10-14 Added dual-wheel configuration (ongoing)
2025-10-20 2 wheel configs and teleop
2025-10-20 2 wheel configs auto calib
2025-10-22 joycon and keyboard ctrl for 2 wheel

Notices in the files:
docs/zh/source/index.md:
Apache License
